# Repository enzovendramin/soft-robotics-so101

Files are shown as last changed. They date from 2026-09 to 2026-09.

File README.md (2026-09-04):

# Soft Tentacle End-Effector for the SO-ARM101

A cable-driven soft tentacle gripper that replaces the rigid gripper of the
[SO-ARM101 / SO-101](https://github.com/TheRobotStudio/SO-ARM100) robot arm,
built to explore soft manipulation and imitation/reinforcement learning for
palletization tasks.

> **Status:** working prototype, written up at the end of the internship so the
> work is not lost. The arm is built, driveable by teleoperation, and has picked
> the test object up and moved it. It is not a finished product. See
> [`docs/next_steps.md`](docs/next_steps.md) for what comes after.

---

## Overview

The stock SO-ARM101 ends in a rigid, 3D-printed parallel-jaw gripper driven by
one servo (motor 6). This project replaces that gripper with a **soft,
tendon-driven tentacle**.

The idea of turning this arm into a soft-robotics platform is **Simo Alami**'s,
who supervised the internship. The tentacle design is inspired by
[SpiRobs](https://github.com/ZhanchiWang/Open-Spiral-Robots) and by the
[Shoggoth Mini](https://github.com/mlecauchois/shoggoth-mini) project.

The design reuses **motor 6 as a winch**: it pulls a single cable that bends the
tentacle, while the existing wrist-roll joint (motor 5) rotates the plane of
curvature. No motors are added, and the HTDCR paper backs this up as a sound
architecture rather than a shortcut (see references).

<p align="center">
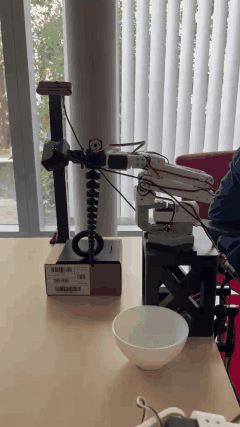
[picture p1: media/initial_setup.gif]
The arm with the tentacle, the ring on its stand and the bowl
  
  <br>
  <em>The setup: the arm on its raised base, the tentacle, the ring on its stand
  and the bowl it goes into.</em>
</p>

### Where the learning fits

A tentacle has no clean model to control against, so learning the task is a
reasonable route.

- **Imitation learning (started).** Demonstrations are recorded by
  teleoperation, with both cameras, into a `LeRobotDataset`. One episode is in
  [`dataset/`](dataset/), and replaying it on the real arm reproduces the pick
  and place.
- **Reinforcement learning (the target).** Once the dataset is large enough,
  the plan is to move on to RL. The open decision is the action space, since
  the winch is not a position-controlled gripper. See
  [`docs/next_steps.md`](docs/next_steps.md).

The recording format was chosen with this in mind: the winch's action is stored
as the raw trigger value, so a trained policy can output the same thing a human
did. See [`docs/design_decisions.md`](docs/design_decisions.md).

### What was built

- A **custom interface support** that bolts where the stock gripper was, cradles
  motor 6, and routes the cable straight down into the tentacle base.
- A **tuner-peg winch** on motor 6, a guitar-tuner-style peg with the cable
  knotted through its shaft, which is what lets the tentacle relax as well as bend.
- A **raised base**, so the tentacle hangs clear of the table and can reach
  down to objects below the arm.
- A **camera mount on interlocking GoPro-style arcs**, giving two set-and-clamp
  rotations, so the webcam rides with the arm and can be re-aimed by hand
  instead of reprinted. The same arcs also fit the rigid claw.
- A **diagnostic/teleoperation CLI** ([`software/robot_tools.py`](software/robot_tools.py))
  including a software multi-turn winch controller, which the STS3215 servo does
  not provide natively.
- **Recording and replay** ([`record_winch.py`](software/record_winch.py),
  [`replay_winch.py`](software/replay_winch.py)) that drive the winch properly
  instead of treating it as a position-controlled gripper.

Replaying a recorded episode, the tentacle picked a toroid ring off its stand
and dropped it in a bowl. Teleoperate, record, replay, working end to end.

## Repository structure

```
.
├── README.md                 <- you are here
├── docs/
│   ├── design_decisions.md   <- why 1 cable, why this architecture, trade-offs
│   ├── lessons_learned.md    <- cable expansion, encoder limits, Windows gotchas
│   ├── next_steps.md         <- more episodes, RL, 3 cables, winch control
│   └── references.md         <- papers, models, and links used
├── hardware/
│   ├── ASSEMBLY.md           <- how to build and assemble everything
│   ├── interface_support/    <- the custom bracket (main contribution)
│   ├── tuner/                <- winch peg that mounts on motor 6
│   ├── tentacle/             <- generated SpiRob body
│   ├── arc_plate/            <- GoPro-style arcs on a bolt-on plate (V5 uses this)
│   ├── camera_mount/         <- webcam support that couples to the arcs
│   ├── rotation_claw/        <- rigid gripper adapted to carry the arc plate
│   ├── base/                 <- raised block and the plate the arm bolts to
│   └── test_objects/         <- grasping targets
├── dataset/                  <- one recorded episode, with both camera videos
├── media/                    <- photos and clips of the build
└── software/
    ├── README.md             <- how to set up the environment from scratch
    ├── robot_tools.py        <- diagnostic/teleop CLI (move, spool, trigger, ...)
    ├── record_winch.py       <- records a dataset with winch control
    ├── replay_winch.py       <- plays a recorded episode back on the arm
    ├── config.py             <- ports, IDs and camera indices
    ├── requirements.txt
    └── s0101code_simo/       <- Simo Alami's pipeline, for the rigid claw
```

## Hardware summary

| Part | Material | Source |
|---|---|---|
| Interface support (bracket) | PLA / PETG | Custom, modeled in Fusion |
| Winch (tuner peg + attachment) | PLA | Custom, guitar-tuner style |
| Tentacle body | TPU 95A | Generated with the OpenSpiRobs tool |
| Camera mount | PLA | Custom arc interface on Simo Alami's wrist mount |
| Raised base | PLA | Custom extension of the stock SO-101 base |
| Cable | 0.5 mm nylon fishing line | Off-the-shelf ([link](https://www.amazon.fr/dp/B0B8N7151L)) |

See [`hardware/ASSEMBLY.md`](hardware/ASSEMBLY.md) for the bill of materials
and step-by-step assembly.

## Software summary

Built on the [LeRobot](https://github.com/huggingface/lerobot) ecosystem
(v0.6.0), on Windows. The arm is a **follower** SO-101, teleoperated from a
paired **leader** arm. See [`software/README.md`](software/README.md) for setup.

Recording and replay needed their own scripts because the winch cannot be
driven as a position-controlled gripper. `software/s0101code_simo/` is Simo
Alami's pipeline, which works for the rigid claw and was the starting point for
mine.

## Credits

- **Simo Alami**, who supervised the internship, proposed converting the arm to
  a soft end-effector, and whose camera mount and LeRobot pipeline this builds
  on.
- **SpiRobs** and **Shoggoth Mini**, for the tentacle design and for showing it
  running on the same STS3215 servos.

## References

Key prior work. See [`docs/references.md`](docs/references.md) for the full
list with DOIs:

- **SpiRobs**: logarithmic-spiral soft robots (Wang, Freris & Wei, *Device*, 2025)
- **Shoggoth Mini**: SpiRob-based tentacle using the same STS3215 servos + LeRobot
- **HTDCR**: hybrid single-tendon continuum robot that avoids torsion (Huertas Niño, Boutayeb & Martinez, *Frontiers in Robotics and AI*, 2025)
- **DEFROST / SOFA**: FEM modeling and control of soft robots (Coevoet, Escande & Duriez, Inria)

## License

No license chosen. This is an internal handoff document, not a public release.
If it is ever published, note that the tentacle generator (OpenSpiRobs) is under
the PolyForm Noncommercial License 1.0.0, and see
[`hardware/ASSEMBLY.md`](hardware/ASSEMBLY.md) for which models are original and
which are only linked.

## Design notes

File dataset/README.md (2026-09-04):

# Dataset

`tentacle_pickplace2/` is one recorded episode, kept here as proof the pipeline
works end to end. It is a `LeRobotDataset` (codebase version 3.0), recorded with
[`../software/record_winch.py`](../software/record_winch.py).

| | |
|---|---|
| Task | *Pick up the toroid with the tentacle and drop it elsewhere* |
| Episodes | 1 |
| Frames | 797 at 30 fps, so about 26 seconds |
| Robot | `so_follower` |
| Size | 7.3 MB, nearly all of it video |

## What is in a frame

| Feature | Type | Shape |
|---|---|---|
| `action` | float32 | 6, the five joints plus the winch trigger |
| `observation.state` | float32 | 6, the same, read back from the arm |
| `observation.images.wrist` | video | 360 × 640, camera on the arm |
| `observation.images.top` | video | 480 × 640, overhead camera |

The sixth number in `action` is **not** a gripper position. It is the leader
trigger's raw 0–100% value, because the winch runs in velocity mode and has no
single position to record. See
[`../docs/design_decisions.md`](../docs/design_decisions.md).

## The two videos

<div align="center">
<table>
<tr>
  <th align="center">Top camera</th>
  <th align="center">Wrist camera</th>
</tr>
<tr>
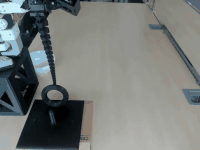
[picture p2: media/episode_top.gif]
Overhead view of the episode
  <td align="center"></td>
  <td align="center">Wrist view of the episode</td>
</tr>
<tr>
  <td align="center"><em>The workspace, with the ring on its stand and the bowl</em></td>
  <td align="center"><em>Rides with the arm, looking down the tentacle</em></td>
</tr>
</table>
</div>

Both show the same episode, sped through at 5 fps. The full-quality mp4s are in
[`tentacle_pickplace2/videos/`](tentacle_pickplace2/videos/), one per camera.

## How it was recorded

Teleoperation from the leader arm, with the winch on bang-bang trigger control
rather than the position-controlled gripper `lerobot-record` expects. One take,
about 26 seconds: pick the ring off its stand, move it across, drop it in the
bowl.

Replaying this episode with
[`../software/replay_winch.py`](../software/replay_winch.py) reproduces the
pick and place on the real arm.

## Using it

The dataset here is a copy. To record more episodes into it, work from the
LeRobot cache copy (`~/.cache/huggingface/lerobot/enzo/tentacle_pickplace2`)
and use `--resume`:

```powershell
python record_winch.py --repo-id enzo/tentacle_pickplace2 --num-episodes 20 `
    --single-task "Pick up the toroid with the tentacle and drop it elsewhere" --resume
```

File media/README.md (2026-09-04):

# Photos

| File | Shows |
|---|---|
| `initial_setup.gif` | The whole setup: arm on its raised base, tentacle, ring on its stand and the bowl. Used at the top of the main README |
| `tuner_motor6_attachment.jpeg` | The tuner bolted to its attachment on motor 6, with the shaft the nylon winds onto |
| `tuner_knot.jpeg` | The nylon wrapped on the tuner shaft and knotted |
| `cable_straight_tuner.jpeg` | The winch, the support and the tentacle together, with the line running from the tuner down into the tentacle |
| `tentacle_support_attachment.jpeg` | The tentacle base slotted into the support, arc plate visible on the side |
| `camera_mount_arcs.jpeg` | The camera clipped onto the arc plate |
| `raised_and_arm_base.jpeg` | The raised block with the ribbed arm plate bolted on top, clamped to the table |
| `episode_top.gif` | The recorded episode from the overhead camera, used in [`../dataset/`](../dataset/) |
| `episode_wrist.gif` | The same episode from the wrist camera |

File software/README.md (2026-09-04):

# Software

Windows 11, LeRobot 0.6.0. Nothing here is Windows-only by design, but the
gotchas at the bottom are.

| File | What it is |
|---|---|
| [`robot_tools.py`](robot_tools.py) | Diagnostics and teleoperation. The tool used to bring the arm up and drive the winch |
| [`record_winch.py`](record_winch.py) | Records a dataset by teleoperation, with winch control instead of a normal gripper |
| [`replay_winch.py`](replay_winch.py) | Replays a recorded episode on the arm |
| [`config.py`](config.py) | COM ports, arm IDs and camera indices. **Edit this first** |
| [`s0101code_simo/`](s0101code_simo/) | Simo Alami's pipeline for the rigid claw. See the bottom |

---

## Setup

```powershell
cd path\to\soft-robotics-so101\software
python -m venv .venv
.venv\Scripts\Activate.ps1
pip install -r requirements.txt
```

If PowerShell refuses to run the activation script:
`Set-ExecutionPolicy -Scope Process -ExecutionPolicy Bypass`

**Plug the power supply into the bus adapter.** USB alone talks to the motors
but will not move them. If everything connects and nothing moves, that is why.

Find the ports and cameras, and put the numbers in `config.py`:

```powershell
lerobot-find-port
lerobot-find-cameras opencv
```

Then calibrate. **Type `c` at the prompt** for a fresh calibration. An old
file gives joint values that look fine but are shifted.

```powershell
lerobot-calibrate --robot.type=so101_follower --robot.port=COM3 --robot.id=my_arm
```

Check it moves: `python robot_tools.py move shoulder_pan --step 10`

---

## `robot_tools.py`

| Command | What it does |
|---|---|
| `move <joint> [--step 10]` | Nudge one joint and read it back |
| `read-leader [--seconds 20]` | Print the leader's positions. The follower does not move |
| `spool` | REPL for the winch: `dir cw/ccw`, `speed`, `torque`, `roll <turns>`, `status` |
| `multiturn [--turns 1]` | Teleop where the leader trigger drives N full turns of the winch |
| `trigger [--high 80] [--low 20]` | Bang-bang winch: trigger past the thresholds spins it one way or the other. `--display_data` opens a Rerun window with both cameras |
| `keyboard [--step 3]` | Keyboard teleoperation |

Defaults come from `config.py`. `--port` and `--id` override them.

**Start with `spool`.** It drives the winch straight from the follower, with no
leader arm in the loop, so you can wind an exact number of turns and watch the
load while it happens. That makes it the quickest way to check the tuner, the
knot and the cable routing before anything depends on teleoperation:

```powershell
python robot_tools.py spool
```

```
dir cw
speed 300
roll 0.5
```

Stop `trigger` and `read-leader` with **ESC**. Ctrl+C only works when the
terminal has focus, and the Rerun window takes it.

The winch commands run the motor in **velocity mode**, because the STS3215
cannot represent a target more than one turn away. If you build on them, add up
the differences between encoder readings. Do not send an absolute position, or
the motor jerks every time it crosses 4095 → 0. See
[`../docs/lessons_learned.md`](../docs/lessons_learned.md#the-motor-only-counts-one-turn).

`safe_stop()` retries a dropped stop command several times and shouts at you to
cut the power if it cannot confirm the motor stopped. Keep that if you
refactor, because a dropped stop leaves the winch winding.

---

## Recording and replaying

`record_winch.py` records a `LeRobotDataset` by teleoperation. It exists
because `lerobot-record` assumes a position-controlled gripper, which cannot
drive the winch.

```powershell
python record_winch.py --repo-id enzo/tentacle_pickplace2 `
    --num-episodes 10 `
    --single-task "Pick up the toroid with the tentacle and drop it elsewhere" `
    --episode-time-s 20 --reset-time-s 10 --display_data

# add more episodes to the same dataset later
python record_winch.py --repo-id enzo/tentacle_pickplace2 --num-episodes 5 `
    --single-task "Pick up the toroid with the tentacle and drop it elsewhere" --resume
```

While recording: **→** ends the episode, **←** re-records the last one,
**ESC** stops.

`replay_winch.py` plays an episode back on the arm, using the same winch
control it was recorded with:

```powershell
python replay_winch.py --repo-id enzo/tentacle_pickplace2 --episode 0
```

The gripper action is recorded as the leader trigger's raw 0–100% value, not a
motor position, so a trained policy can output the same thing and have it run
through the same zone logic. See
[`../docs/design_decisions.md`](../docs/design_decisions.md).

---

## `s0101code_simo/`

Simo Alami's LeRobot pipeline: dataset recording, ACT training, evaluation,
replay, multi-camera teleoperation. I used it as the starting point for the
winch scripts, and it works as-is for the **rigid claw**, not the tentacle.

Two things to know before running it:

- It pins **lerobot 0.4.1** on Python 3.10 in a conda environment
  (`lerobot.yml`), so it does not import under the 0.6.0 install used by
  `robot_tools.py`. Keep the two environments separate.
- `S0101_evaluate.py` imports `S0101_policy_utils`, which is not in the folder.

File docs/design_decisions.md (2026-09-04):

# Design decisions

Each section is a problem and what I did about it.

---

## 1. Driving the tentacle without adding motors

**Problem.** A tendon-driven tentacle needs something to pull its cable, and the
arm already has all six of its motors doing a job.

**What I did.** Motor 6 used to open and close the gripper. Now it winds a
single cable that bends the tentacle. Only two stock parts come off,
`Moving_Jaw_SO101` and `Wrist_Roll_Follower_SO101`, so the change is reversible:
reprint those and the normal gripper goes back on.

Why one cable:

- **Nothing new to add.** Same 6 motors, same bus, same power supply. Extra
  motors would also put extra weight right at the end of the arm, which is the
  worst place for it.
- **The other motors do the aiming.** Motor 5 rotates the plane the tentacle
  bends in, and joints 1 to 4 move the whole wrist. Between them you can put
  that plane wherever the task needs it, so one bending direction is not the
  limit it sounds like.
- **It is a known design, not a shortcut.** The HTDCR paper (Huertas Niño et
  al., 2025) builds a continuum robot the same way, one tendon to bend and a
  rotating base to aim, and shows it twists *less* under load than versions with
  several tendons.
- **Less to go wrong.** With several cables you have to keep the tension matched
  across all of them. With one there is a single thing to control.

**The cost.** The tentacle bends in one plane at a time, so you aim first and
bend second instead of commanding a direction directly. Bending any way at once
needs three cables. See [`next_steps.md`](next_steps.md).

---

## 2. Aiming the camera: the arc mounts

**Problem.** The camera has to keep the tentacle tip and the work area in frame,
and the angle that does that depends on the object and where it sits. Bolting it
on at a fixed angle means a reprint every time the setup changes.

**What I did.** A GoPro-style arc interface, which you set by hand and clamp.
The point is not to save prints, it is to keep the option open: whatever angle
you pick, you can change it later without touching the design.

No motor for this, on purpose. It would add a servo and its weight at the end
of the arm for something you set and leave alone.

The bracket went through three versions getting there:

- **V3**: the three arcs are part of the bracket, all the same thickness.
- **V4**: same idea, outer arc thicker to take the load, inner one thinner since
  it was not bending anyway.
- **V5**: the arcs come off the bracket completely. In their place a pocket for a
  heat-set insert, so a separate arc plate bolts on. That adds a second
  adjustable axis, and the arc part can be changed without reprinting the piece
  that holds the motor.

The camera mount clips onto this interface and you aim it by hand. The arcs
live on their own plate (`Rotation_Plate`), and that plate also glues onto an
adapted rigid claw (`Rotation_Claw`), which means the camera mounts identically
whether the arm has the tentacle or the normal jaws on it.

---

## 3. The tentacle, and hanging it clear of the table

**Problem.** The tentacle has to bend far, hold its shape under its own weight,
and actually grip something. And once it is mounted, the wrist sits low enough
that it touches the table.

**What I did.** Generated the tentacle with the **OpenSpiRobs** tool, which
makes the log-spiral shape, using dimensions close to an existing SpiRob that
was already known to work rather than guessing my own. The cable hole is bigger
than the reference so the line is easier to thread. Printed in TPU 95A with the
printer's default profile.

The spiral is what makes it grip. The tip curls first and the rest follows, so
it wraps around an object instead of shoving it away.

For the clearance, the base was extended to lift the whole arm off the table.

---

## 4. What the dataset records for the winch

**Problem.** A normal gripper has a position you can record. The winch does not.
It runs in velocity mode and can turn several times, so no single number means
"the gripper is here".

**What I did.** Record what the operator did instead: the leader trigger's raw
0 to 100% value. That maps onto the zone logic the winch already uses, which is
wind one way past the high threshold, the other way past the low one, stop in
between.

Two things this buys:

- The dataset keeps its normal shape, one number per joint including the
  gripper, so nothing downstream needs special-casing.
- A trained policy can output that same number and have it run through the same
  zones, instead of a `Goal_Position` the winch cannot use.

It is also why replaying needs `replay_winch.py` and not `lerobot-replay`. The
stock replay would send that 0 to 100% value as a position, and the winch would
move a fraction of a turn instead of winding.

---

## Open questions

None of these are answered, and all three need more use than I gave them:

- **How much tension the cable needs at rest.** Not tested.
- **Whether the clamped arcs hold long term.** They held their angle over
  repeated use, but not enough use to say for certain.
- **How much the tentacle can lift.** Same answer. It carried the test object
  fine, but I never loaded it far enough to find the limit.

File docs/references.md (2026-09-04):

# References

Papers, tools, and models this project builds on.

---

## Core architecture

**A hybrid tendon-driven continuum robot that avoids torsion under external load**
Maria Paula Huertas Niño, Mohamed Boutayeb, Dominique Martinez.
*Frontiers in Robotics and AI* 12:1576209, 2025. Open access (CC BY).
[doi:10.3389/frobt.2025.1576209](https://doi.org/10.3389/frobt.2025.1576209)

> The key justification for this project's architecture. Bending from a
> **single tendon** with lateral joints constraining the bending plane, plus a
> **rotary base** for orientation. Reports negligible out-of-plane deviation
> (millimetre range), *smaller* in-plane tip deflection than a 4-tendon
> continuum robot, and a 450 g payload. This is why "1 cable + rotation" is
> treated here as a sound choice rather than a simplification.

**SpiRobs: Logarithmic spiral-shaped robots for versatile grasping across scales**
Zhanchi Wang, Nikolaos M. Freris, Xi Wei.
*Device* 3, 100646, 2025.
[doi:10.1016/j.device.2024.100646](https://doi.org/10.1016/j.device.2024.100646)

> The tentacle geometry. A log-spiral taper actuated by two or three cables,
> 3D printed in TPU, with an octopus-inspired grasping strategy. The tip curls
> first and the body follows, so the tentacle wraps rather than pushes.

**3D printed cable-driven continuum robots with generally routed cables: modeling and experiments**
Soumya Kanti Mahapatra, Ashwin K. P., Ashitava Ghosal. arXiv, 2020.
[arXiv:2003.04593](https://arxiv.org/abs/2003.04593)

> Background on cable-driven continuum robots: how cable routing determines the
> achievable shapes, and kinematic vs. Cosserat-rod modelling of the result.

**Design and Experiment of a Soft Gripper Based on Cable-Driven Continuum Structures**
Qiong Wu, Zhenglong Yi, Hongqiang Wang, Han Yuan. IEEE ROBIO 2021.
[doi:10.1109/ROBIO54168.2021.9739279](https://doi.org/10.1109/ROBIO54168.2021.9739279)

> A five-finger soft gripper built from cable-driven continuum fingers, with
> stiffness deliberately redistributed along each finger so it envelops an
> object instead of bending uniformly, which is relevant to the spine-thickness choice
> made here.

---

## FEM modelling and control (Inria / DEFROST)

**Optimization-Based Inverse Model of Soft Robots With Contact Handling**
Eulalie Coevoet, Adrien Escande, Christian Duriez.
*IEEE Robotics and Automation Letters*, 2017.
[doi:10.1109/LRA.2017.2669367](https://doi.org/10.1109/LRA.2017.2669367) ·
[hal-01500912](https://inria.hal.science/hal-01500912v1)

**Soft robots locomotion and manipulation control using FEM simulation and quadratic programming**
Eulalie Coevoet, Adrien Escande, Christian Duriez.
IEEE RoboSoft 2019.
[doi:10.1109/ROBOSOFT.2019.8722815](https://doi.org/10.1109/ROBOSOFT.2019.8722815) ·
[hal-02079151](https://inria.hal.science/hal-02079151v1)

> The research-grade control path: simulate the soft body with FEM in SOFA and
> solve an optimisation for the actuation that achieves a desired pose. Out of
> scope for this internship.

---

## Software and tools

| Resource | Use here |
|---|---|
| [LeRobot](https://github.com/huggingface/lerobot) (v0.6.0) | Robot drivers, teleoperation, dataset recording, ACT training |
| [SOFA Framework](https://www.sofa-framework.org/) | FEM simulation of soft bodies (future work) |
| [SOFA SoftRobots plugin](https://project.inria.fr/softrobot/) | Soft-robot modelling and inverse control in SOFA |

## Hardware sources

| Resource | Use here |
|---|---|
| [SO-ARM100 / SO-101](https://github.com/TheRobotStudio/SO-ARM100) | The base arm. Stock parts, print files, and the gripper this project replaces |
| [Shoggoth Mini](https://github.com/mlecauchois/shoggoth-mini) | A SpiRob tentacle running on the same STS3215 servos and LeRobot. The reference I sized the tentacle against |
| [Open-Spiral-Robots (OpenSpiRobs)](https://github.com/ZhanchiWang/Open-Spiral-Robots) | The parametric design tool used to generate the tentacle body (PolyForm Noncommercial 1.0.0) |

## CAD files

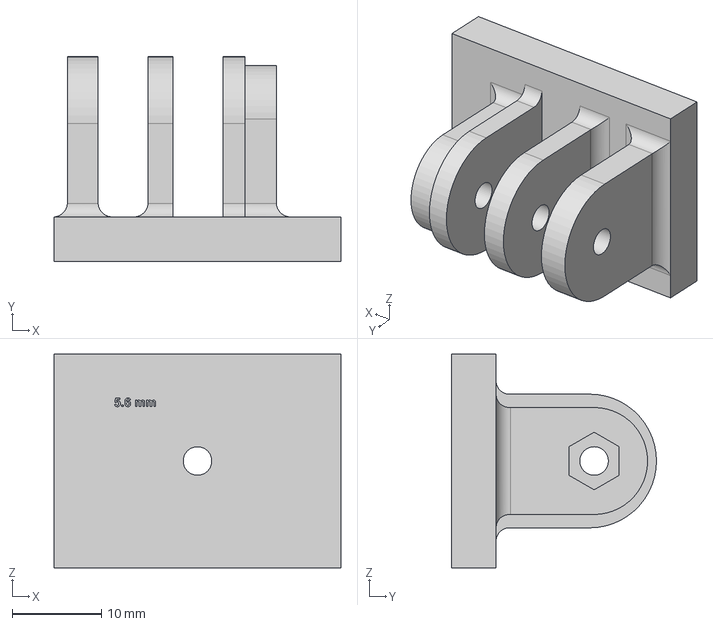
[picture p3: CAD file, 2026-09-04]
hardware/arc_plate/Rotation_Plate.step
32.2 x 23.0 x 24.0 mm

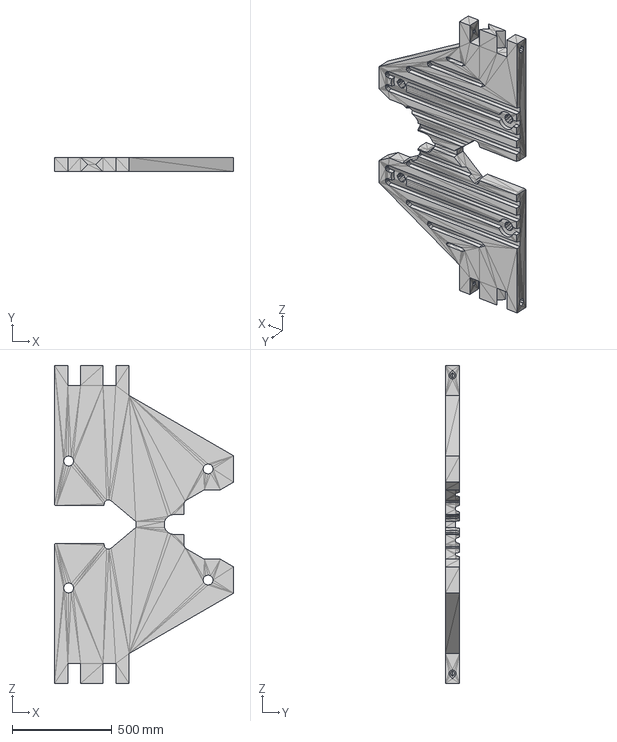
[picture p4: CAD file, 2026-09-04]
hardware/base/arm_base.step
896.0 x 72.0 x 1590.4 mm

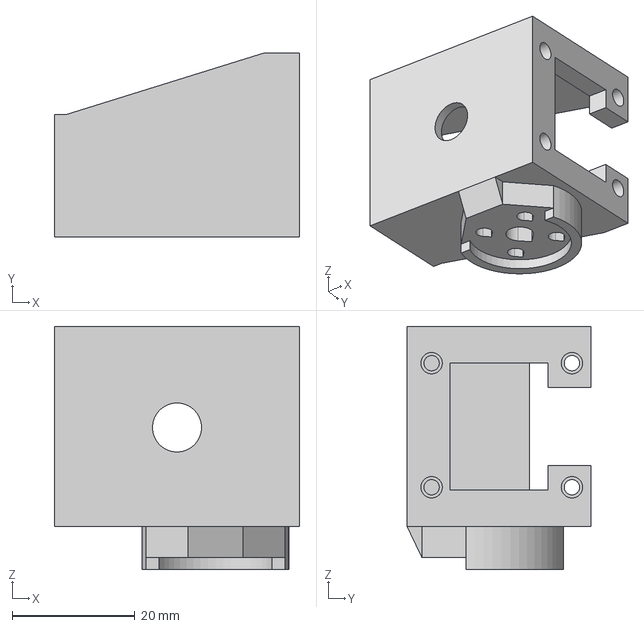
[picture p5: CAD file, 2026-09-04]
hardware/interface_support/Support.step
40.0 x 30.0 x 39.7 mm

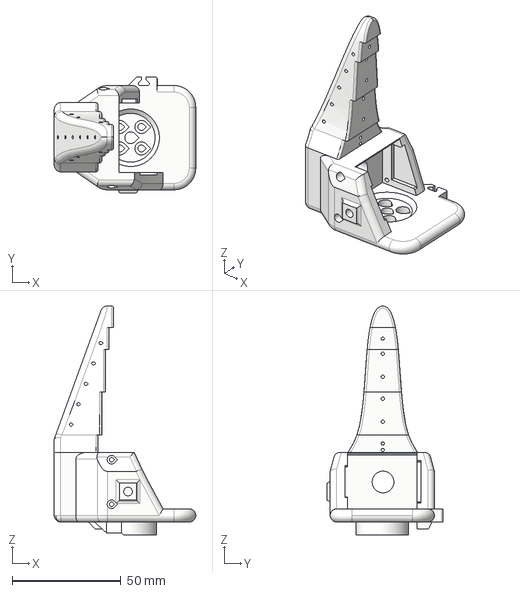
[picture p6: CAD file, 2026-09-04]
hardware/rotation_claw/Rotation_Claw.step
65.2 x 53.5 x 105.4 mm

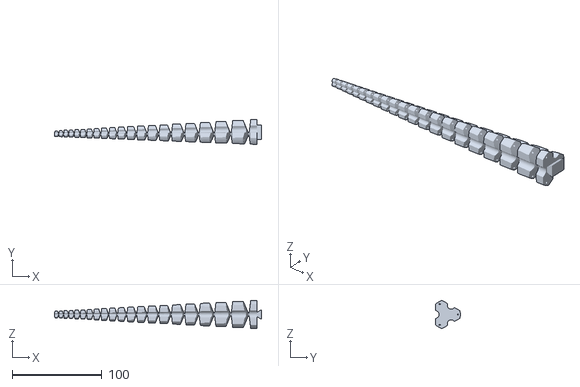
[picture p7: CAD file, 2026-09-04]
hardware/tentacle/spirobs.stl
231.3 x 27.8 x 31.4

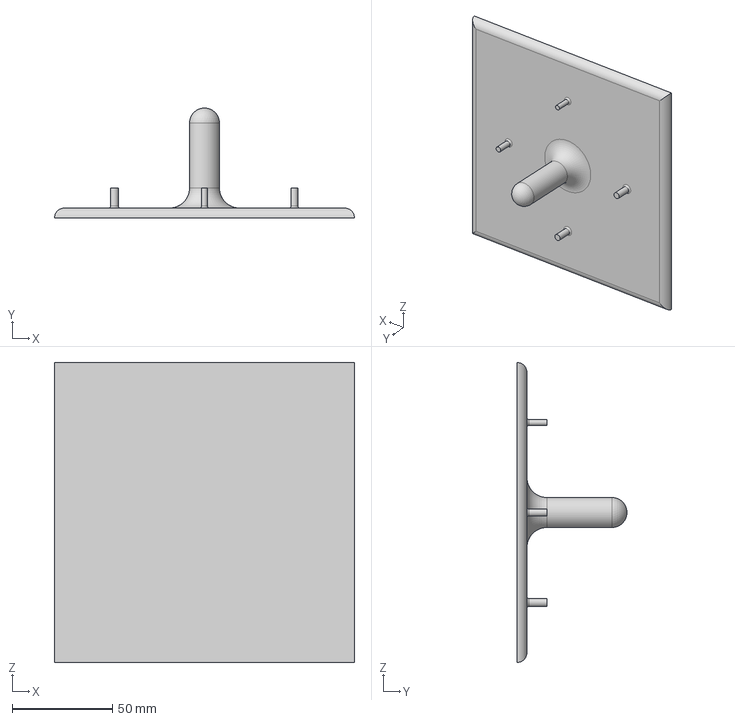
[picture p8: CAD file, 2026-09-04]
hardware/test_objects/StickV2.step
150.0 x 55.0 x 150.0 mm

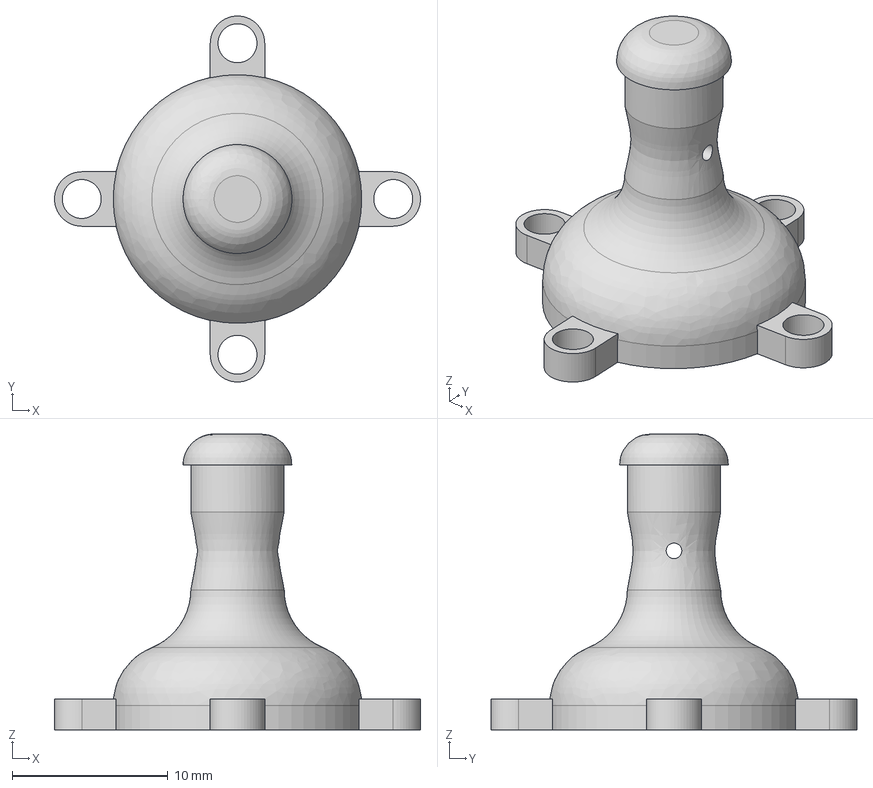
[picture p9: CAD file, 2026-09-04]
hardware/tuner/Tuner.step
23.5 x 23.5 x 19.0 mm

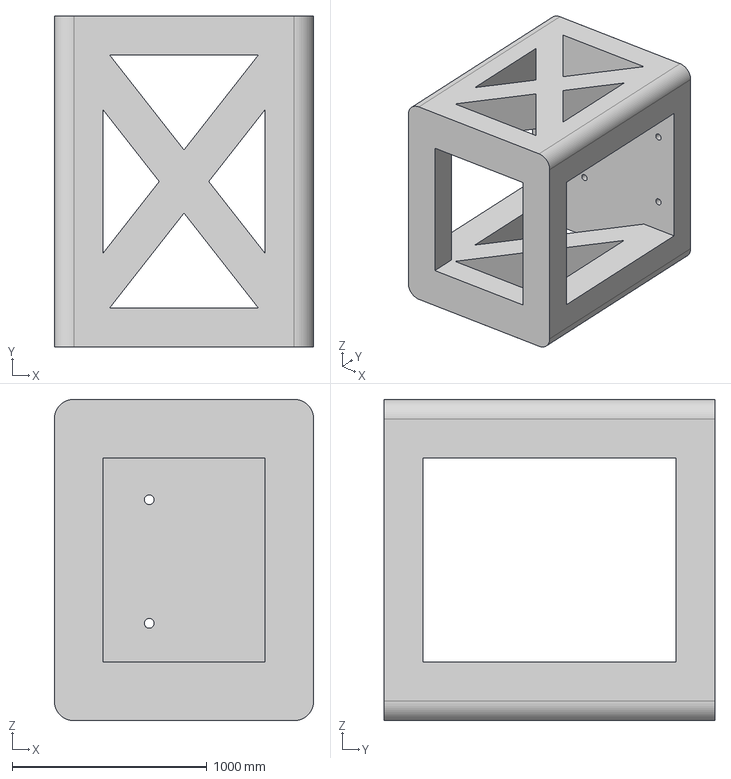
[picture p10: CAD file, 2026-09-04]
hardware/base/Raised_Base.step
1332.3 x 1700.0 x 1650.0 mm

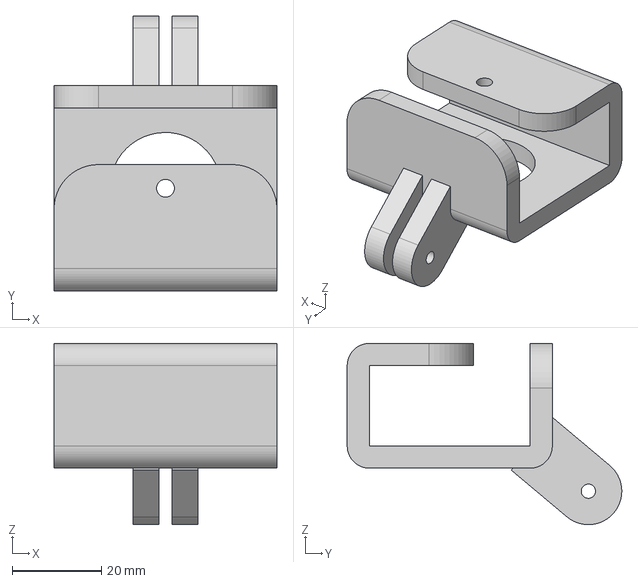
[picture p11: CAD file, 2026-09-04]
hardware/camera_mount/Webcam_Mount_Wrist_custom_v4.step
50.0 x 61.6 x 40.6 mm

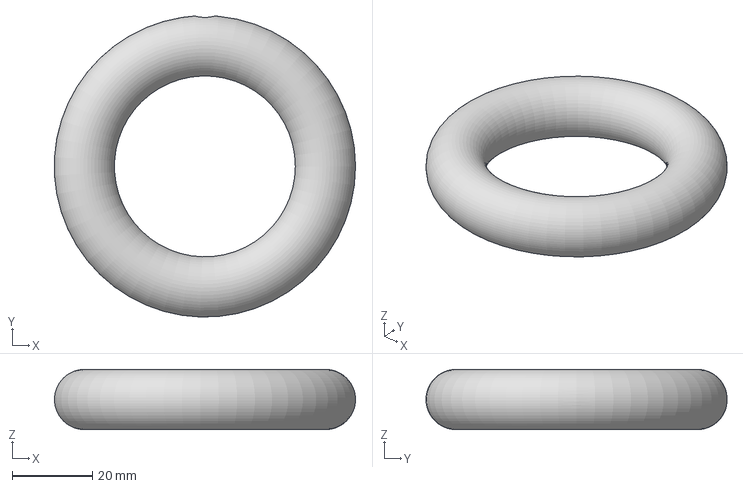
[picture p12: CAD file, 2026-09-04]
hardware/test_objects/Ring.step
74.9 x 74.9 x 15.0 mm

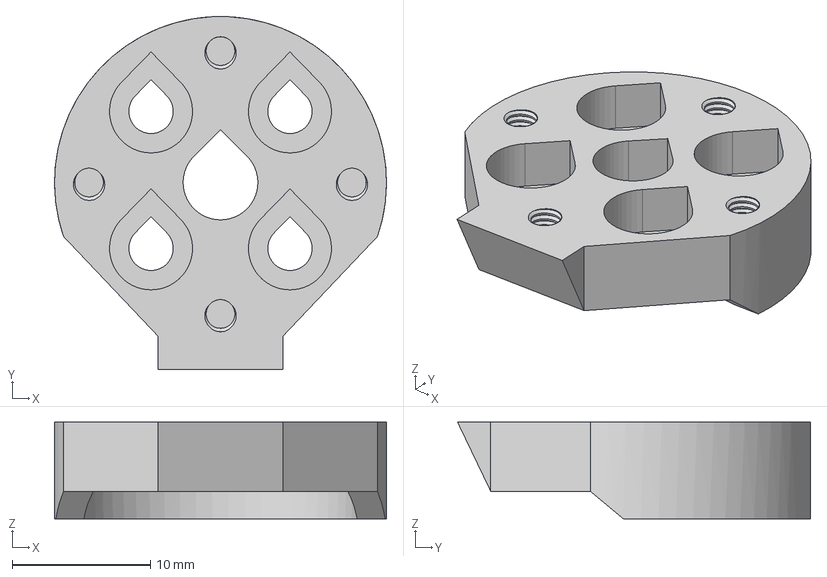
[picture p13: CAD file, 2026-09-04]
hardware/tuner/TunerAttachment.step
24.0 x 25.5 x 7.00 mm

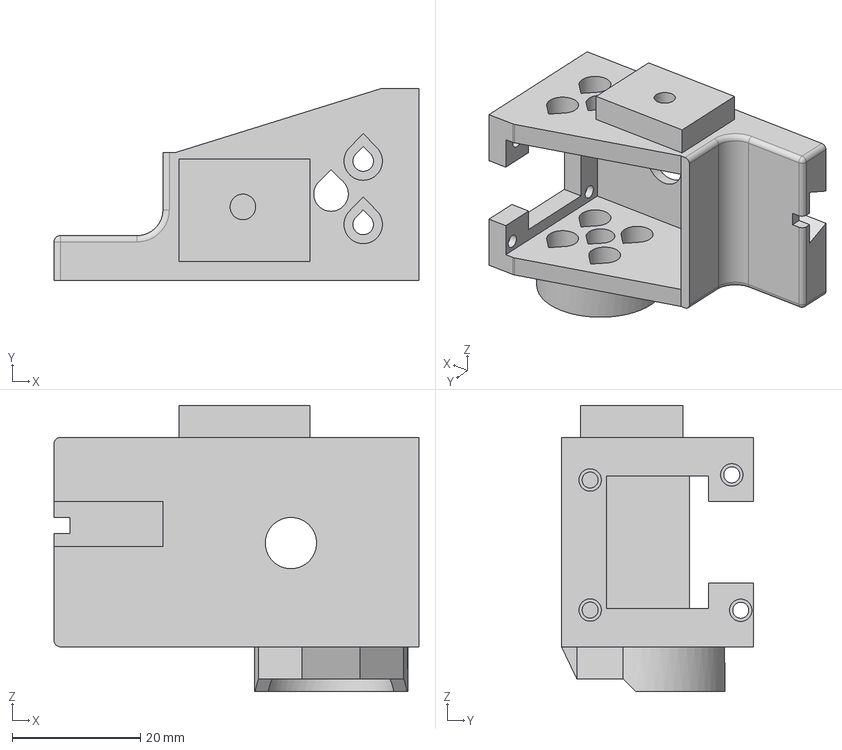
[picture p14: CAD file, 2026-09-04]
hardware/interface_support/SupportV5.step
57.0 x 30.0 x 44.7 mm

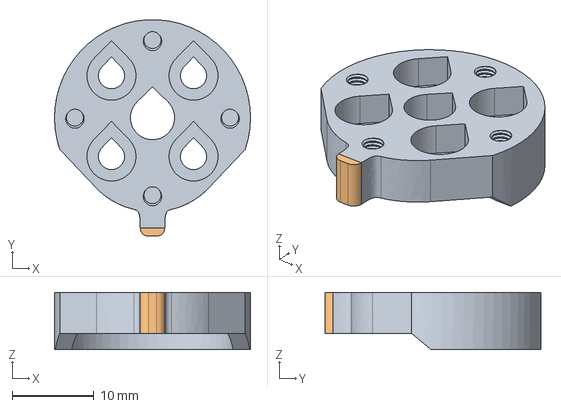
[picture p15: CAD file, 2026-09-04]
hardware/tuner/TunerAttachmentV2.step
24.0 x 26.5 x 7.00 mm

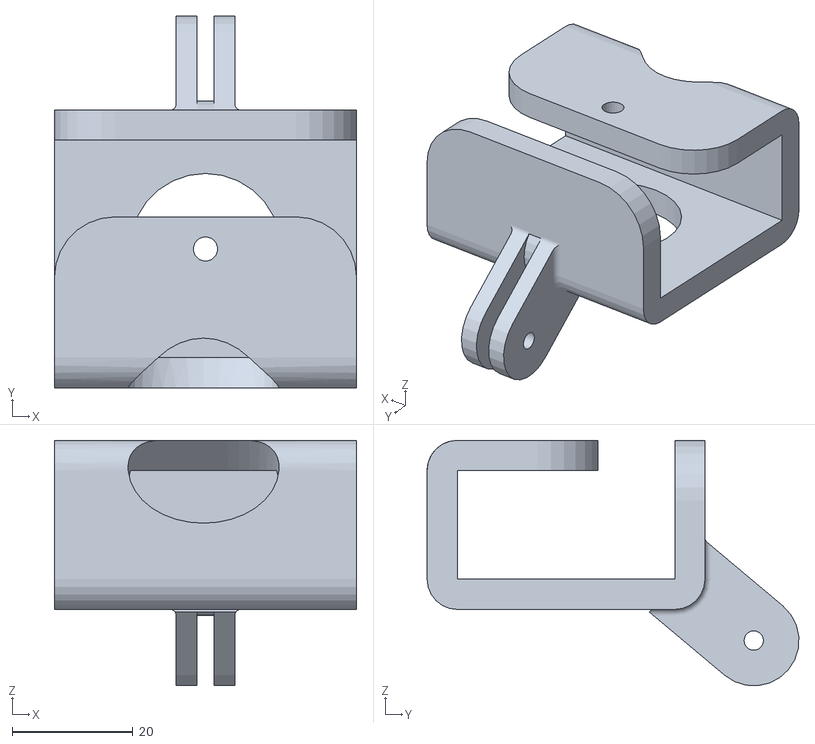
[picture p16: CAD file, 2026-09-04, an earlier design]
hardware/camera_mount/Webcam_Mount_Wrist_customV3.stl
50.0 x 61.6 x 40.6

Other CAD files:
hardware/interface_support/SupportV3.stl
hardware/interface_support/SupportV4.step
hardware/arc_plate/Rotation_Plate.stl
hardware/base/Raised_Base.stl
hardware/base/arm_base.stl
hardware/camera_mount/Webcam_Mount_Wrist_custom_v4.stl
hardware/interface_support/Support.stl
hardware/interface_support/SupportV4.stl
hardware/interface_support/SupportV5.stl
hardware/rotation_claw/Rotation_Claw.stl
hardware/test_objects/StickV2.stl
hardware/tuner/Tuner.stl
hardware/tuner/TunerAttachment.stl
hardware/tuner/TunerAttachmentV2.stl

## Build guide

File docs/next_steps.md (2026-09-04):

# Next steps

## Where I stopped

The build is finished and works. The tentacle is mounted, the winch pulls it,
and the whole thing is driveable by teleoperation with both cameras running.

I started recording a dataset with `record_winch.py`, and wrote
`replay_winch.py` to play an episode back on the arm. Replaying a recorded
episode, the tentacle **picked the toroid ring off its stand and dropped it in
a bowl**. That is the task working end to end: teleoperate, record, replay.

The dataset so far is one episode, `enzo/tentacle_pickplace2`, 797 frames at
30 fps.

---

## 1. More episodes

One episode is enough to prove the pipeline, not to train anything. The next
job is to record a lot more of them, with the object starting in different
places so a policy sees more than one approach.

```powershell
python record_winch.py --repo-id enzo/tentacle_pickplace2 --num-episodes 20 `
    --single-task "Pick up the toroid with the tentacle and drop it elsewhere" --resume
```

Worth deciding early: whether every episode uses the same ring, or whether
other shapes go in too. Mixing them makes a harder dataset but a more useful
policy.

---

## 2. Reinforcement learning

The plan after the dataset is RL rather than imitation alone.

The reward is the easy part. The top camera already sees the bowl, so whether
the ring ended up in it is straightforward to read off.

The decision worth making early is the action space: whether the policy outputs
the trigger value directly, the way the dataset is recorded (see
[`design_decisions.md`](design_decisions.md)), or something closer to cable
length.

Two practical warnings for anyone running the arm unattended:

- The winch can wind itself to destruction if a stop command gets dropped. Keep
  `safe_stop()` in the loop.
- Never let the cable go fully slack, or it unwraps from the tuner.

---

## 3. Three cables

The mechanical follow-up: three cables instead of one, so the tentacle can bend
in any direction without turning motor 5.

The tentacle side is already solved: the OpenSpiRobs tool generates 2- and
3-cable bodies. The work is in where the two extra motors go. Stacking them at
joint 5 is the obvious option, and worth checking the arm still handles the
added weight at the wrist before committing to it. Mounting them lower down
with the cables routed up is the alternative if it does not.

This is a trade, not a straight upgrade: the single-cable design twists less
under load (see [`design_decisions.md`](design_decisions.md)).

---

## 4. Better winch control

- Tension feedback instead of position alone, so the residual tension is
  measured rather than guessed.
- Measure tip angle against winch turns, so a controller can be asked for a
  curvature rather than a number of turns.

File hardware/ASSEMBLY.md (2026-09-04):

# Assembly

How to build the tentacle end-effector onto an SO-101 arm.

---

## Parts

### Printed

| Part | File | Material |
|---|---|---|
| Interface support | `SupportV5.stl` | PLA or PETG |
| Arc plate | `Rotation_Plate.stl` | PLA or PETG |
| Tuner | `Tuner.stl` | PLA |
| Tuner attachment | `TunerAttachmentV2.stl` | PLA |
| Tentacle | `spirobs.stl` | TPU 95A |
| Raised base | `Raised_Base.stl` + `arm_base.stl` | PLA |
| Camera mount | `Webcam_Mount_Wrist_custom_v4.stl` | PLA |

Printed with the printer's default profile, no tuning needed. The tentacle is
the only slow one.

### Everything else

| Item | Qty |
|---|---|
| M3 screws, support to joint 5 | 4 |
| Small screws, motor 6 into the support | 2 |
| M3 screw + heat-set insert, arc plate onto the support | 1 each |
| M3 screw + heat-set insert, camera onto its mount | 1 each |
| M4 screws + heat-set inserts, arm onto the raised base | 4 each |
| 0.5 mm nylon fishing line ([this one](https://www.amazon.fr/dp/B0B8N7151L)) | ~1 m |
| Webcam | 1 |

Nylon works best. Guitar string and twine were both tried and both do the job
up to a point, but nylon is the one to use. See
[`../docs/lessons_learned.md`](../docs/lessons_learned.md#the-cable-comes-off-the-winch-unless-you-knot-it).

---

## Steps

### 1. Print

Start with the tentacle. It is the longest print, and its base diameter decides
whether the support socket fits.

### 2. Strip the wrist

Remove `Moving_Jaw_SO101` and `Wrist_Roll_Follower_SO101`. Leave motor 6 on the
bus; it becomes the winch. Nothing below joint 5 changes.

### 3. Fit the tuner

`TunerAttachmentV2` mounts on motor 6. `Tuner` bolts onto it through the four
ears around its dome. The tuner's shaft has a hole across it for the nylon, and
when motor 6 turns the nylon winds around the shaft and pulls the tentacle.

<p align="center">
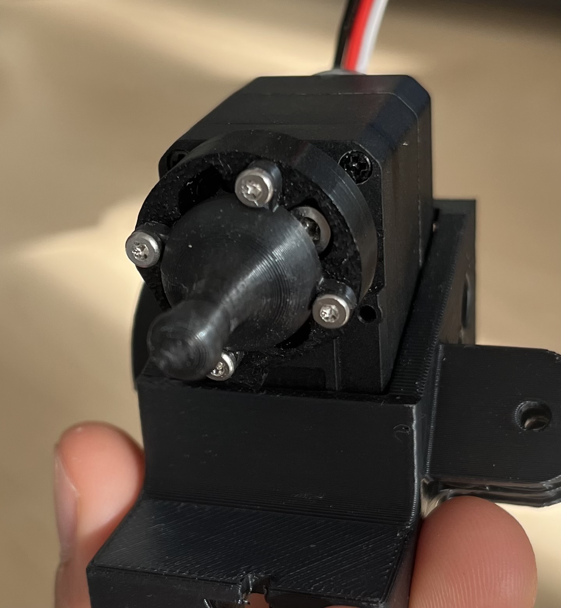
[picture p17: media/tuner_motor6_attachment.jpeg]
The tuner bolted to its attachment on motor 6
  
  <br>
  <em>The tuner bolts on through the four ears. The hole for the nylon is in the shaft sticking out of the middle.</em>
</p>

### 4. Bolt the support to joint 5

4× M3 into the pattern the old gripper used. Drop motor 6 into its cradle and
hold it with the 2 small screws.

**Check the alignment before going further:** the cable hole in the tentacle
socket has to sit directly under the tuner. If the cable comes off at an angle
it rubs the edge of the hole, which eats winch torque and wears the line
through.

<p align="center">
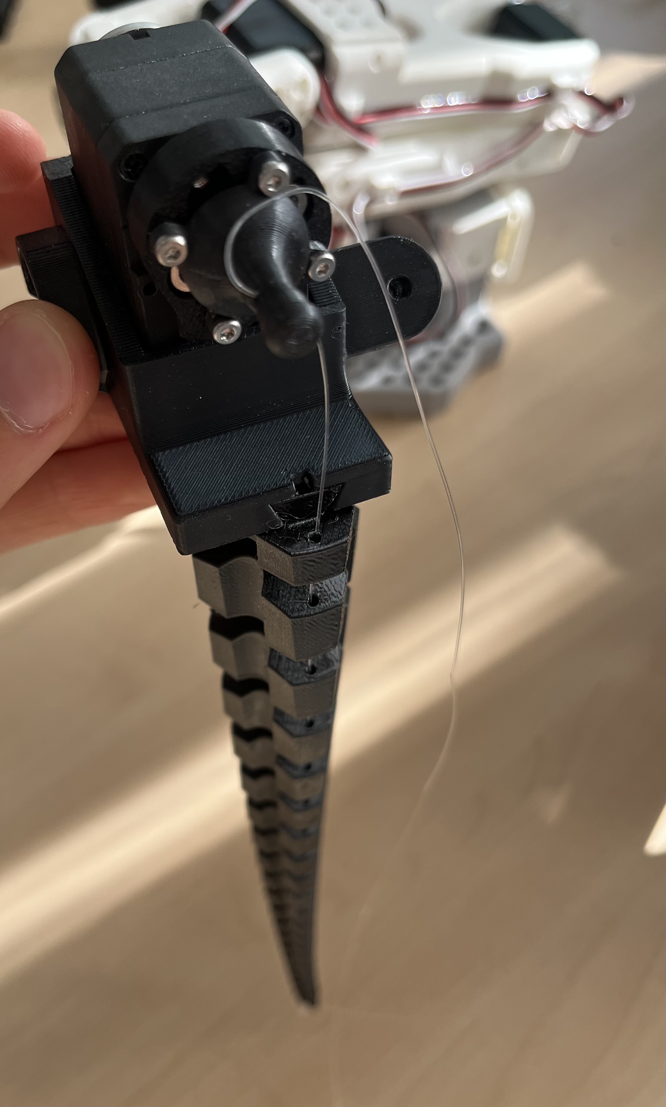
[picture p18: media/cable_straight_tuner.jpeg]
The cable running from the tuner down into the tentacle
  
  <br>
  <em>The line should drop straight from the tuner into the hole, like this, not off to one side.</em>
</p>

### 5. Fit the arc plate

Bolt `Rotation_Plate` onto the support with one M3 into a heat-set insert. This
is the mount the camera clips onto in step 9.

Both arc joints are set by hand and clamped, so you can aim the camera later
without reprinting anything. Leave them loose for now and set the angles once
the camera is on.

### 6. Mount the raised base

Two parts. `Raised_Base` is the block that lifts everything, and `arm_base` is
the ribbed plate that bolts on top. The arm screws onto it with four M4 into
heat-set inserts.

The base lifts the arm so the tentacle hangs clear of the table instead of
dragging on it. **Clamp the base to the table.** With the arm raised it is not
stable on its own.

<p align="center">
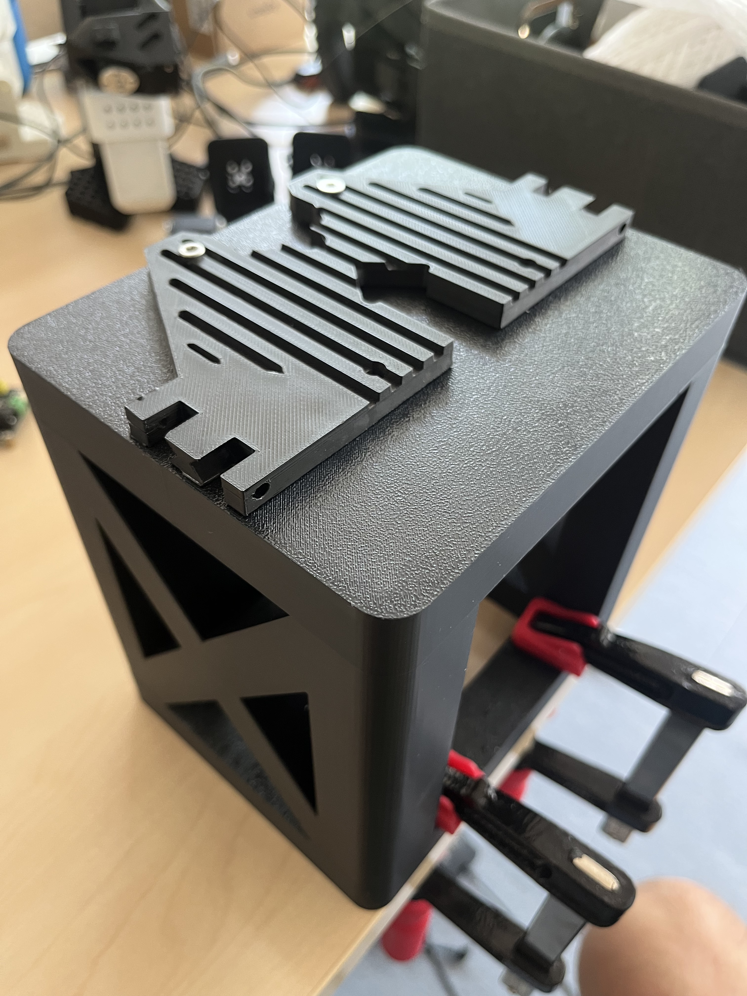
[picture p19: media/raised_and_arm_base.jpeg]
The raised base with the arm base plate on top
  
  <br>
  <em>The raised block with the ribbed plate bolted on top. The clamps holding it to the table are behind it.</em>
</p>

### 7. Thread the cable

Tip of the tentacle → down the internal channel → out the base → through the
hole in the support → through the hole in the tuner shaft → **tie a knot**.

> **Do not skip the knot.** Without it the line is only held by the friction of
> its own wrap, and it will not pay back out when the motor reverses. The
> tentacle bends in and never straightens.

Wind it on in the direction that bends the tentacle when motor 6 winds in.
Check by hand first. Leave a little tension on it at rest.

<p align="center">
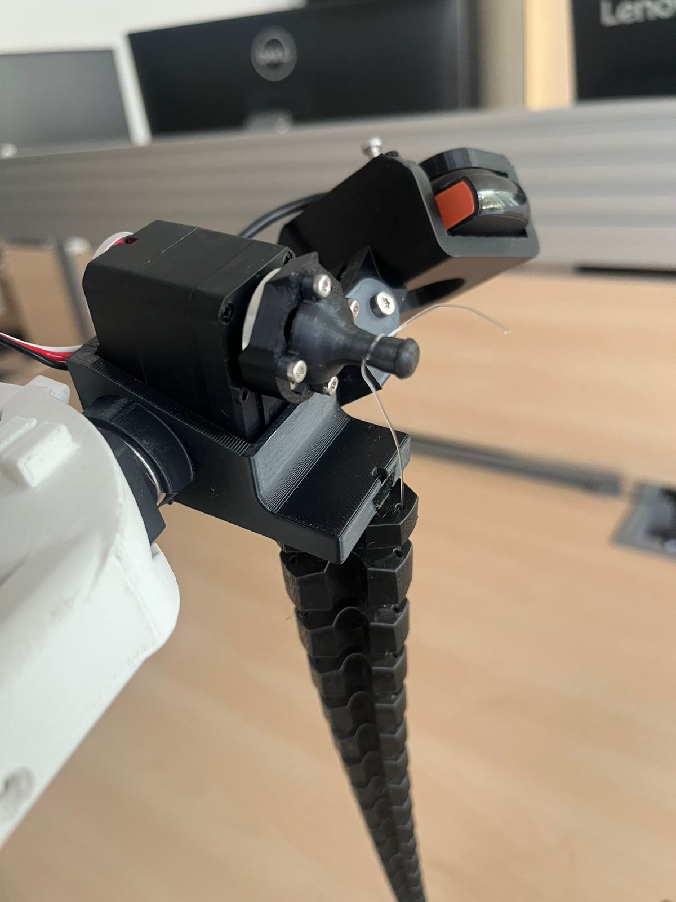
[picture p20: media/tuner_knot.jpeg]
The nylon knotted on the tuner shaft
  
  <br>
  <em>The line wrapped on the shaft and knotted on the far side.</em>
</p>

### 8. Seat the tentacle

The tentacle base has a trapezoidal shape that slots into the support. No glue,
no screw. Push it in until it seats.

<p align="center">
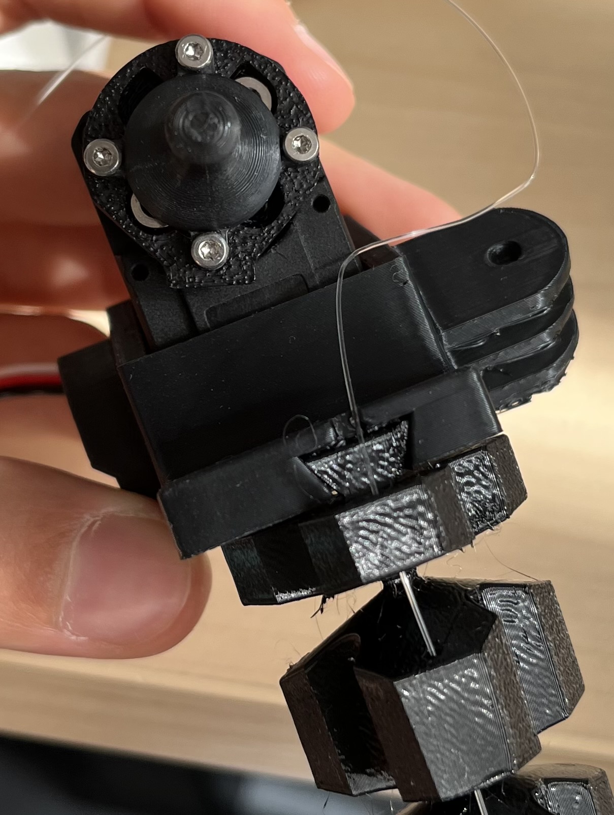
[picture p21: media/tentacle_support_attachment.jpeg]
The tentacle base seated in the support
  
  <br>
  <em>The tentacle base slotted into the support, with the arc plate on the right.</em>
</p>

### 9. Mount the camera

Clip the camera mount onto the arc plate from step 5, aim it by hand, and clamp
both arc joints. Keep the tentacle tip and the work area in frame.

<p align="center">
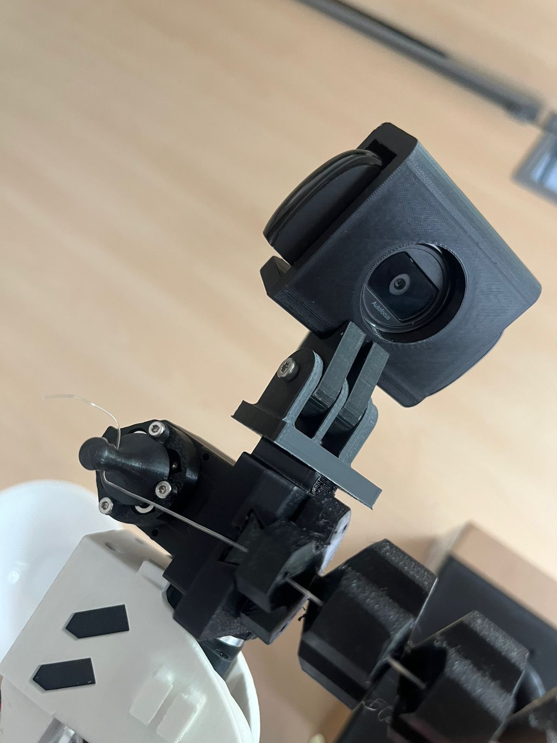
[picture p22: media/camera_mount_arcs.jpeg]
The camera clipped onto the arc plate
  
  <br>
  <em>The camera on the arcs, above the tuner and the tentacle.</em>
</p>

### 10. Recalibrate and test

The wrist mass changed, so recalibrate. Type `c` for a fresh calibration.

```powershell
lerobot-calibrate --robot.type=so101_follower --robot.port=COM3 --robot.id=my_arm
```

Then test the winch a little at a time:

```powershell
python robot_tools.py spool
```

```
dir cw
speed 300
roll 0.5
```

Watch the load numbers and increase the turns slowly. Keep a hand near the
power switch. A dropped stop command can leave the winch spinning, and the
tentacle will wind itself up until something breaks.

---

## Files

| Folder | What is in it |
|---|---|
| `interface_support/` | The bracket. V5 is the one to print; V3 and V4 are kept too |
| `arc_plate/` | The three GoPro arcs on a plate. V5 bolts to this, and the camera mount clips onto it |
| `tuner/` | The winch: the tuner peg and the attachment that holds it on motor 6. Print `TunerAttachmentV2`, which rounds off the corner you push on when setting motor 6 by hand. V1 is kept too |
| `tentacle/` | The generated SpiRob body, STL only |
| `camera_mount/` | Webcam support, adapted from Simo Alami's design |
| `rotation_claw/` | The rigid gripper claw, adapted so the arc plate glues onto it |
| `base/` | The raised block and the ribbed plate the arm bolts to |
| `test_objects/` | `Ring`, the target for the tentacle to grab, and `StickV2`, the stand it sits on |

Not committed here, get them from the source instead: stock SO-101 parts and
`Raised_Base_Extension` from [SO-ARM100](https://github.com/TheRobotStudio/SO-ARM100),
and the Shoggoth Mini reference parts from
[Shoggoth Mini](https://github.com/mlecauchois/shoggoth-mini).

Fusion `.f3d` files are gitignored. Export STEP/STL here instead.

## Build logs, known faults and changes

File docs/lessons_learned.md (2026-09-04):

# Lessons learned

Things that cost me time, written down so the next person does not hit them
again.

---

## The cable comes off the winch unless you knot it

Stiff line does not stay wrapped on a smooth shaft. When the tension drops it
springs off, the wrap goes loose, and the next time the motor pulls it takes up
that slack before it does anything useful. So the same motor angle stops giving
you the same bend.

The fix is the tuner. `Tuner` has a hole through its shaft, the nylon goes
through that hole, and **you tie a knot on the other side**.

The knot is not optional. Without it the line is only held by friction, and it
will not come back out when the motor turns the other way. The tentacle bends
in fine and then never straightens. If that happens to you, check the knot
first.

### Cables I tried

- **Guitar string.** Hard to wind and too springy. It fights the tuner.
- **Twine.** Winds on the tuner really well, and I used it to check the winch
  worked at all, by tying an object to it and lifting it. The problem is that it
  is floppy, so you cannot push it through the small holes in the tentacle. A
  cable you can push is worth more here than a strong one.
- **Nylon fishing line, 0.5 mm.** What I ended up using:
  <https://www.amazon.fr/dp/B0B8N7151L> (100 m, sold as ~21 kg). Goes through
  the tentacle easily and winds fine with the knot. Shoggoth Mini uses 0.5 mm
  too.

Using the twine first was useful because it split the problem in two: does the
winch work, and does the cable fit. One question at a time.

One thing I would still do if I carried on: stop the software ever leaving the
cable completely slack, and keep a little tension on it at rest. Nothing in the
code does that today, and how much tension it needs was never measured.

---

## The motor only counts one turn

The STS3215 encoder goes 0–4095 over one turn and does not count how many turns
you have done. I checked, and there is no multi-turn mode in `scservo_sdk` or in
LeRobot's Feetech table. For a winch that needs several turns, that is a
problem.

Two things follow:

- You cannot use `Goal_Position`, because it cannot describe a target more than
  one turn away. The winch has to run in **velocity mode**.
- You have to count the turns yourself in software, by adding up the
  *differences* between readings. If you convert to an absolute position and
  send that instead, you get a big jump every time the encoder passes 4095 → 0,
  and the motor jerks.

[`software/robot_tools.py`](../software/robot_tools.py) already does this.
`multiturn` keeps a running total and drives the motor by velocity, while the
other five joints work normally. `spool` lets you wind an exact number of
turns, counted on the encoder instead of by timing.

**What I actually ended up using is simpler.** Recording and replay
(`record_winch.py`, `replay_winch.py`) do not track turns at all. They use
bang-bang zone control: past the high threshold wind one way, past the low one
wind the other, stop in between. Counting turns matters if you want to command a
position; for driving the winch by hand and recording what you did, the zones
are enough. `multiturn` is still there if you need the count.

---

## The bus drops commands when the motor is loaded

You get `RuntimeError` / "Input voltage error" while the winch is pulling.

LeRobot's own `num_retry` retries immediately, one after another, so all the
tries can land in the same voltage dip and all fail. Waiting a few tens of
milliseconds between tries works much better.

The dangerous case is when the failed command is `Goal_Velocity = 0`. If that
one gets dropped, the motor keeps spinning. `robot_tools.py` retries the stop
several times and prints a warning telling you to cut the power by hand if it
cannot confirm the motor stopped. Keep that if you rewrite it.

---

## Building and mounting the parts

- **Leave room for the screwdriver.** Partway through I had to cut extra space
  into the support and into the camera mount, because there was no room to get
  a screw in. Check that before printing, not after.
- **Getting the motor into the support** works well but takes a few tries to
  get the feel for it. Use the lower pressure hole.
- **Watch the weight and the torque** if you change the design. Everything you
  add sits at the end of the arm, and the motors have to hold it.
- **Round off anything you push with a finger.** Motor 6 has to be turned by
  hand to its neutral position fairly often, and the first tuner attachment had
  a sharp corner right where you push. V2 rounds it. Small change, and you
  notice it every time.

---

## Windows and LeRobot

- **Ports are `COMx`.** Find them with `lerobot-find-port`. The number can
  change if you plug into a different USB port or through a dock, so they live
  in [`software/config.py`](../software/config.py) instead of in every script.
- **`so_follower` vs `so101_follower`.** Both are right, in different places:

  ```python
  from lerobot.robots.so_follower import SO101Follower, SO101FollowerConfig   # works
  from lerobot.robots.so101_follower import SO101Follower                     # fails
  ```
  ```powershell
  lerobot-calibrate --robot.type=so101_follower --robot.port=COM3 --robot.id=my_arm
  ```

  The import path is `so_follower`, but `so101_follower` is still the right
  name for `--robot.type` on the command line. The module used to be called
  `so101_follower` and was renamed, which is why `s0101code_simo/` does not
  import: it pins lerobot 0.4.1 and `robot_tools.py` runs on 0.6.0. Check your
  version before copying an import from the internet.
- **Redo the calibration, do not reuse it.** Type `c` at the prompt. An old
  calibration file gives you joint values that look fine but are shifted.
- **PowerShell uses a backtick** to continue a line, not a backslash. Linux
  docs will give you the wrong one.
- **`--display_data` needs an extra you may not have.** The Rerun viewer comes
  from `rerun-sdk`, which lerobot only pulls in with its `viz` extra. Install
  `lerobot[feetech,viz]`, or the flag fails on a clean environment.
- **Stop with ESC, not Ctrl+C**, in the commands that open a Rerun window. The
  viewer takes the focus, and Ctrl+C only reaches the program while the terminal
  has it.

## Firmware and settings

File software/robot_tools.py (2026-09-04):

"""
Manual testing/diagnostic CLI for the SO-101 leader/follower pair.
Consolidates the one-off scripts used to validate hardware before running
lerobot-teleoperate / lerobot-record.

Usage:
  python robot_tools.py move shoulder_pan --step 10
  python robot_tools.py move wrist_flex --step 15 --wait 1.0
  python robot_tools.py read-leader --seconds 20
  python robot_tools.py spool
  python robot_tools.py multiturn --turns 1
  python robot_tools.py trigger --high 80 --low 20 --speed 800
  python robot_tools.py trigger --high 80 --low 20 --speed 800 --display_data
  python robot_tools.py keyboard
"""

import argparse
import time

from config import CAMERA_TOP_INDEX, CAMERA_WRIST_INDEX, FOLLOWER_ID, FOLLOWER_PORT, LEADER_ID, LEADER_PORT


def retry_call(fn, attempts=3, delay=0.05):
    """Call fn() up to `attempts` times, sleeping `delay` seconds between
    failures. The Feetech bus's own num_retry retries back-to-back with no
    pause, which doesn't help against a brief voltage sag (tens of ms) --
    all instant retries can land inside the same bad window. A short real
    delay gives the rail a chance to recover before the next attempt.
    Returns (True, result) on success, (False, None) if all attempts fail."""
    for i in range(attempts):
        try:
            return True, fn()
        except RuntimeError as e:
            if i == attempts - 1:
                print(f"\n  [failed after {attempts} attempts: {e}]")
            else:
                time.sleep(delay)
    return False, None


def safe_stop(bus, motor, attempts=5):
    """Best-effort emergency stop: a single failed 'Goal_Velocity=0' write
    (e.g. the transient 'Input voltage error' seen under load) must never be
    allowed to leave the motor spinning uncommanded, so this retries several
    times before giving up and loudly warning the user."""
    for i in range(attempts):
        try:
            bus.write("Goal_Velocity", motor, 0, num_retry=2)
            return True
        except RuntimeError as e:
            print(f"\n  [stop attempt {i + 1}/{attempts} failed: {e}]")
            time.sleep(0.1)
    print("\n  !!! COULD NOT CONFIRM THE MOTOR STOPPED -- CUT POWER MANUALLY IF IT'S STILL MOVING !!!")
    return False


def read_hot(bus, motor):
    """Load/current/temp (no voltage) -- cheap enough for tight control loops.
    Returns None on a transient bus/servo error (e.g. the Feetech 'Input
    voltage error' seen under load) instead of raising, so callers can stop
    the motor safely."""
    try:
        load = bus.read("Present_Load", motor, normalize=False)
        current_a = bus.read("Present_Current", motor, normalize=False) * 0.0065
        temp_c = bus.read("Present_Temperature", motor, normalize=False)
        return load, current_a, temp_c
    except RuntimeError as e:
        print(f"\n  [read error: {e}]")
        return None


def cmd_move(args):
    from lerobot.robots.so_follower import SO101Follower, SO101FollowerConfig

    config = SO101FollowerConfig(port=args.port, id=args.id)
    robot = SO101Follower(config)
    robot.connect()

    obs = robot.get_observation()
    print("\n--- initial positions ---")
    for name, value in obs.items():
        print(f"{name}: {value:.1f}")

    joint_key = f"{args.joint}.pos"
    if joint_key not in obs:
        robot.disconnect()
        raise SystemExit(f"Unknown joint '{args.joint}'. Options: {[k.removesuffix('.pos') for k in obs]}")
    start = obs[joint_key]

    input("\npress ENTER to start the routine (Ctrl+C to cancel)...")

    print(f"\nmoving {args.joint} by {args.step:+.1f} deg")
    robot.send_action({joint_key: start + args.step})
    time.sleep(args.wait)
    reached = robot.get_observation()[joint_key]
    print(f"  readback -> {reached:.1f}")

    print(f"\nreturning {args.joint} to start")
    robot.send_action({joint_key: start})
    time.sleep(args.wait)

    print("\n--- summary ---")
    print(f"{args.joint}: requested {start + args.step:.1f}, readback {reached:.1f} (start {start:.1f})")

    input("\nhold the arm and press ENTER to disconnect...")
    robot.disconnect()
    print("disconnected.")


def cmd_read_leader(args):
    from lerobot.teleoperators.so_leader import SO101Leader, SOLeaderTeleopConfig

    config = SOLeaderTeleopConfig(port=args.port, id=args.id)
    teleop = SO101Leader(config)
    teleop.connect()

    print(f"\nMove the leader by hand. Printing for ~{args.seconds:.0f}s. Ctrl+C to stop early.\n")
    try:
        start = time.time()
        while time.time() - start < args.seconds:
            action = teleop.get_action()
            line = "  ".join(f"{k}={v:6.1f}" for k, v in action.items())
            print(line, end="\r")
            time.sleep(0.2)
    except KeyboardInterrupt:
        pass

    print("\n\ndisconnecting...")
    teleop.disconnect()
    print("disconnected.")


def cmd_spool(args):
    """Interactive REPL to test the gripper motor as a cable winch/spool.
    Keeps the connection open and switches Operating_Mode to VELOCITY, so
    each 'roll' is fast to issue without reconnecting every time.

    Commands:
      dir cw | dir ccw   set direction
      speed <value>      set Goal_Velocity magnitude
      torque <0-1000>    set Torque_Limit
      roll <turns>       spin exactly N full spool turns (tracked via the
                          encoder, not a time guess), streaming telemetry
      status             print one telemetry snapshot
      quit               stop and disconnect
    """
    from lerobot.motors.feetech import OperatingMode
    from lerobot.robots.so_follower import SO101Follower, SO101FollowerConfig

    config = SO101FollowerConfig(port=args.port, id=args.id)
    robot = SO101Follower(config)
    robot.connect()

    bus = robot.bus
    motor = "gripper"
    resolution = bus.model_resolution_table[bus.motors[motor].model]

    bus.disable_torque(motor)
    bus.write("Operating_Mode", motor, OperatingMode.VELOCITY.value)
    bus.enable_torque(motor)

    direction = 1
    speed = 300

    # Raw-unit conversions per Feetech STS/SMS datasheet convention
    # (not independently verified against this exact firmware revision):
    # Present_Current: 6.5 mA/unit, Present_Voltage: 0.1 V/unit,
    # Present_Load: signed, magnitude/1000 = fraction of rated torque.

    def read_status():
        """Full telemetry incl. voltage and the configured torque limit. Used only for the
        low-frequency 'status' command."""
        load = bus.read("Present_Load", motor, normalize=False)
        current_a = bus.read("Present_Current", motor, normalize=False) * 0.0065
        voltage_v = bus.read("Present_Voltage", motor, normalize=False) * 0.1
        temp_c = bus.read("Present_Temperature", motor, normalize=False)
        torque_limit = bus.read("Torque_Limit", motor, normalize=False)
        return load, current_a, voltage_v, temp_c, torque_limit

    def roll(turns):
        target_ticks = turns * resolution
        prev_pos = bus.read("Present_Position", motor, normalize=False)
        traveled = 0.0
        peak_load, peak_current, peak_temp = 0, 0.0, 0
        ok, _ = retry_call(lambda: bus.write("Goal_Velocity", motor, direction * speed))
        if not ok:
            print("  [failed to start]")
            return
        print(f"\nrolling {turns} turn(s), direction={'CW' if direction > 0 else 'CCW'}, speed={speed}")
        try:
            while traveled < target_ticks:
                ok, pos = retry_call(lambda: bus.read("Present_Position", motor, normalize=False))
                if not ok:
                    break
                delta = pos - prev_pos
                if delta > resolution / 2:
                    delta -= resolution
                elif delta < -resolution / 2:
                    delta += resolution
                traveled += abs(delta)
                prev_pos = pos

                status = read_hot(bus, motor)
                if status is None:
                    break
                load, current_a, temp_c = status
                peak_load = max(peak_load, abs(load))
                peak_current = max(peak_current, current_a)
                peak_temp = max(peak_temp, temp_c)
                print(
                    f"  turns={traveled / resolution:5.2f}/{turns}  load={load / 10:6.1f}%  "
                    f"current={current_a:5.2f}A  temp={temp_c:3d}C",
                    end="\r",
                )
                time.sleep(0.1)
        except KeyboardInterrupt:
            print("\n  interrupted")
        finally:
            safe_stop(bus, motor)
        print(f"\n  done. peak load={peak_load / 10:.1f}%  peak current={peak_current:.2f}A  peak temp={peak_temp}C")

    def live_keys():
        import keyboard

        print("\nHold D (or Right arrow) to spin CW, A (or Left arrow) to spin CCW. Release to stop. ESC to exit.\n")
        prev_pos = bus.read("Present_Position", motor, normalize=False)
        net_turns = 0.0
        while True:
            if keyboard.is_pressed("esc"):
                break
            if keyboard.is_pressed("d") or keyboard.is_pressed("right"):
                cmd_speed = speed
            elif keyboard.is_pressed("a") or keyboard.is_pressed("left"):
                cmd_speed = -speed
            else:
                cmd_speed = 0
            ok, _ = retry_call(lambda: bus.write("Goal_Velocity", motor, cmd_speed))
            if not ok:
                safe_stop(bus, motor)
                break

            ok, pos = retry_call(lambda: bus.read("Present_Position", motor, normalize=False))
            if not ok:
                break
            delta = pos - prev_pos
            if delta > resolution / 2:
                delta -= resolution
            elif delta < -resolution / 2:
                delta += resolution
            net_turns += delta / resolution
            prev_pos = pos

            status = read_hot(bus, motor)
            if status is None:
                break
            load, current_a, temp_c = status
            print(
                f"  turns={net_turns:6.2f}  cmd_speed={cmd_speed:5d}  load={load / 10:6.1f}%  "
                f"current={current_a:5.2f}A  temp={temp_c:3d}C",
                end="\r",
            )
            time.sleep(0.05)

        safe_stop(bus, motor)
        print(f"\n  exited keys mode. net turns={net_turns:.2f}")

    print("\nSpool test REPL. Commands:")
    print("  dir cw | dir ccw    set direction (used by 'roll')")
    print("  speed <value>       set Goal_Velocity magnitude (e.g. 500)")
    print("  torque <0-1000>     set Torque_Limit")
    print("  roll <turns>        spin N full turns in the current direction, streaming telemetry")
    print("  keys                live control: hold D/Right = CW, A/Left = CCW, ESC = exit")
    print("  status              print a single telemetry snapshot")
    print("  quit                stop and disconnect\n")

    while True:
        try:
            raw = input("> ").strip().lower()
        except (EOFError, KeyboardInterrupt):
            break
        if not raw:
            continue
        parts = raw.split()
        cmd = parts[0]

        if cmd in ("quit", "exit", "q"):
            break
        elif cmd == "dir" and len(parts) == 2:
            direction = 1 if parts[1] in ("cw", "1", "+") else -1
            print(f"direction set to {'CW' if direction > 0 else 'CCW'}")
        elif cmd == "speed" and len(parts) == 2:
            speed = int(parts[1])
            print(f"speed set to {speed}")
        elif cmd == "torque" and len(parts) == 2:
            value = max(0, min(1000, int(parts[1])))
            bus.write("Torque_Limit", motor, value)
            print(f"Torque_Limit set to {value}")
        elif cmd == "roll" and len(parts) == 2:
            try:
                turns = float(parts[1])
            except ValueError:
                print("usage: roll <turns>")
                continue
            roll(turns)
        elif cmd == "keys":
            live_keys()
        elif cmd == "status":
            try:
                load, current_a, voltage_v, temp_c, torque_limit = read_status()
                print(
                    f"load={load / 10:.1f}%  current={current_a:.2f}A  voltage={voltage_v:.1f}V  "
                    f"temp={temp_c}C  torque_limit={torque_limit}/1000"
                )
            except RuntimeError as e:
                print(f"[read error: {e}]")
        else:
            print("unknown command")

    safe_stop(bus, motor)
    bus.disable_torque(motor)
    bus.write("Operating_Mode", motor, OperatingMode.POSITION.value)
    robot.disconnect()
    print("disconnected (gripper reset back to position mode).")


def cmd_multiturn(args):
    """Custom teleop loop: the leader's gripper trigger (proportional, single
    turn) drives N full turns of the follower's gripper/winch motor.

    The STS3215 has no native multi-turn mode (confirmed: absent from both
    scservo_sdk and lerobot's Feetech control table), so this tracks the
    follower's "unwrapped" cumulative position in software by integrating
    wrap-corrected deltas of Present_Position, and closes a velocity
    P-controller around the error against a target derived from the leader's
    0-100% reading. Goal_Position can't represent multi-turn targets, so the
    gripper is driven in VELOCITY mode throughout, not POSITION mode. The
    other 5 joints teleoperate normally (position mode) in the same loop.

    Stop with ESC (works regardless of which window has focus -- Ctrl+C only
    works if the terminal itself is focused).
    """
    import keyboard

    from lerobot.motors.feetech import OperatingMode
    from lerobot.robots.so_follower import SO101Follower, SO101FollowerConfig
    from lerobot.teleoperators.so_leader import SO101Leader, SOLeaderTeleopConfig

    teleop = SO101Leader(SOLeaderTeleopConfig(port=args.leader_port, id=args.leader_id))
    robot = SO101Follower(SO101FollowerConfig(port=args.port, id=args.id))
    teleop.connect()
    robot.connect()

    bus = robot.bus
    motor = "gripper"
    resolution = bus.model_resolution_table[bus.motors[motor].model]
    turn_ticks = args.turns * resolution

    bus.disable_torque(motor)
    bus.write("Operating_Mode", motor, OperatingMode.VELOCITY.value)
    bus.write("Torque_Limit", motor, args.torque)
    bus.enable_torque(motor)

    # Sync the unwrapped estimate to the leader's current reading so the
    # follower doesn't jump on the first iteration.
    leader_pct = teleop.get_action()[f"{motor}.pos"]
    prev_leader_pct = leader_pct
    est_ticks = (leader_pct / 100.0) * turn_ticks
    prev_raw = bus.read("Present_Position", motor, normalize=False)
    still_count = 0

    period = 1.0 / args.hz
    print(
        f"\nMulti-turn teleop: leader gripper -> {args.turns} follower turn(s). "
        f"Kp={args.kp}  max_speed={args.max_speed}  torque_limit={args.torque}/1000  "
        f"deadband={args.deadband} ticks  @ {args.hz}Hz.\n"
        f"Hold-on-release: leader still for {args.still_iters} ticks (delta<{args.still_delta}%) -> force stop.\n"
        "ESC (or Ctrl+C) to stop.\n"
    )

    last_print = 0.0
    try:
        while True:
            if keyboard.is_pressed("esc"):
                print("\nstopped (ESC)")
                break

            loop_start = time.time()
            action = teleop.get_action()

            # Other 5 joints: normal position teleop.
            other_action = {k: v for k, v in action.items() if not k.startswith(f"{motor}.")}
            robot.send_action(other_action)

            # Gripper: unwrap the follower's actual position and close a
            # velocity loop around the leader-driven multi-turn target.
            ok, raw = retry_call(lambda: bus.read("Present_Position", motor, normalize=False))
            if not ok:
                safe_stop(bus, motor)
                break
            delta = raw - prev_raw
            if delta > resolution / 2:
                delta -= resolution
            elif delta < -resolution / 2:
                delta += resolution
            est_ticks += delta
            prev_raw = raw

            leader_pct = action[f"{motor}.pos"]
            target_ticks = (leader_pct / 100.0) * turn_ticks

            # Hold-on-release: once the leader stops changing for a few
            # ticks in a row, snap the estimate to the target and force a
            # hard stop instead of chasing a possibly drifted error forever.
            # This is what makes releasing the leader immediately responsive.
            if abs(leader_pct - prev_leader_pct) < args.still_delta:
                still_count += 1
            else:
                still_count = 0
            prev_leader_pct = leader_pct

            held = still_count >= args.still_iters
            if held:
                est_ticks = target_ticks

            error = target_ticks - est_ticks
            if held or abs(error) < args.deadband:
                speed_cmd = 0.0
            else:
                speed_cmd = max(-args.max_speed, min(args.max_speed, args.kp * error))
            ok, _ = retry_call(lambda: bus.write("Goal_Velocity", motor, int(speed_cmd)))
            if not ok:
                safe_stop(bus, motor)
                break

            if time.time() - last_print > 0.2:
                status = read_hot(bus, motor)
                telemetry = (
                    f"load={status[0] / 10:5.1f}%  current={status[1]:4.2f}A  temp={status[2]:2d}C"
                    if status is not None
                    else "load=  ??%  current=??A  temp=??C"
                )
                print(
                    f"  leader={action[f'{motor}.pos']:5.1f}%  target={target_ticks / resolution:5.2f}t  "
                    f"actual={est_ticks / resolution:5.2f}t  error={error / resolution:6.2f}t  "
                    f"speed_cmd={int(speed_cmd):5d}  {'HOLD' if held else '    '}  {telemetry}",
                    end="\r",
                )
                last_print = time.time()

            time.sleep(max(0.0, period - (time.time() - loop_start)))
    except KeyboardInterrupt:
        print("\nstopped by user")
    finally:
        safe_stop(bus, motor)
        bus.disable_torque(motor)
        bus.write("Operating_Mode", motor, OperatingMode.POSITION.value)
        teleop.disconnect()
        robot.disconnect()
        print("disconnected (gripper reset back to position mode).")
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
